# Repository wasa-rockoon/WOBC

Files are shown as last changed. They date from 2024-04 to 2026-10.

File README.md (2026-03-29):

View this project on [CADLAB.io](https://cadlab.io/project/27502). 

# WOBC

WOBCは，WASAロケットプロジェクトにおける電装関連の共通基盤を確立することを目的としたプロジェクトである．
開発した回路や基板の設計情報，プログラムといった資産を再利用しやすい形で整備することで，
開発スピードを向上させるとともに引き継ぎや教育を効率的に行えるようにする．

# 用語

## ユニット

単独で動作する，システムの基本単位．例：ロケット電装，CanSat電装，地上局

1つ以上のモジュールから構成される．

## モジュール

コンポーネントを一枚の基板上に配置した，物理的な単位．例：地上局モジュール，通信モジュール

モジュールには必ずマイコンが含まれ，コンポーネントを制御する．
ユニットを構成するモジュール間はバスで接続される．

## コンポーネント

ユニットを構成する，意味のある一つの機能単位．例：電源管理，姿勢決定，モーター駆動

ハードウェアおよびプログラムはコンポーネント単位で開発する．

## パケット

ユニットやコンポーネント間でやり取りするデータの形式．
詳しくは[WCPP](https://github.com/wasa-rockoon/WCPP)を参照．

# 開発

モジュールやコンポーネントは，全てこのリポジトリに格納する（Monorepoスタイル）．

## Gitの運用

- 開発者ごとに，`develop/your_name` ブランチを作成する．
- 全体に反映したい変更ができたらPull Requestを作成し，責任者にレビューを依頼する．
- コンポーネントおよびモジュール作成の際は自分のブランチとは別に，`feature/CompornentOrModule_name`ブランチを作成する．
- コンポーネント・モジュールが完成したらPull Requestを作成し，責任者にレビューを依頼する．
- 責任者は変更をレビューし，問題なければ`main`ブランチにマージする．（回路・基板のレビューには[CADLAB.io](https://cadlab.io/project/27502)を使うと便利)

## Github Copilotの学生無料

昨今コーディング作業に`AI Agent`の活用が主流になってきていると思います．ただ無料枠で利用していてもすぐトークンを使い切ってしまったり，選べるモデルが少なかったりと不便なことが多いかと思います．そこで個人的にはGithub Copilotの学生無料を利用することを推奨しています．導入方法については`ドキュメント`にあるリンクから参照してください．

## 作業ログ

`Github Copilot`の利用にあわせて，作業ログを作ることを習慣化してほしいと思います．おもにコーディング作業についてですが，

- 前にも同じようなエラーが出てたけど，どうやって解消したんだっけとか
- 過去にも似たようなもの作ってたらしいけど，資料が残っていないとか

色々と引継ぎが上手くいっていないような事象を見かけます．非常にもったいないというか二度手間なことが多いので，ちゃんとノウハウを蓄積できるようにしましょう．

具体的には `docs`のフォルダに`env:`毎でフォルダを作りその中で[template](docs/template.md)を参考にしてAIに作らせてください．タスク毎に作るのが良いかと思います．

# ドキュメント

- [develop](docs/develop.md): 詳細な開発の手順
- [kicad](docs/kicad.md): KiCADを用いた回路・基板設計マニュアル
- [github-copilot](docs/github-copilot.md): Github Copilotの導入マニュアル
- [components](docs/components.md): コンポーネントとその機能，インターフェースの一覧
- [modules](docs/modules.md): モジュールとその機能，構成コンポーネントの一覧
- [unit](docs/unit.md): ユニット一覧
- [library](docs/library.md): WOBCライブラリの使い方

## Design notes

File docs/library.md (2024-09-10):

# WOBCライブラリの使い方

`src/library`下にあるWOBCライブラリによって，コンポーネントやモジュールのソフトウェアを書くための機能が提供される．

# WOBCシステムアーキテクチャ

WOBC上でのソフトウェアでは，複数のコンポーネントが並行に実行され，それらの間のデータのやり取りがwcppパケットを用いたコマンドやテレメトリにより行われる．バスに送信されたパケットは，CANバスで繋がれた他のモジュール上で実行されているものも含めた他の全てのコンポーネントに届けられる．コンポーネントはコマンド（や必要に応じてテレメトリ）を受信し処理を行う．

パケット処理等の機能は`src/library/kernel`によって提供される．具体的には，パケットのデータ領域を確保する参照カウンタを備えたヒープ，コンポーネントに必要なパケットを振り分ける機能等が含まれる．

これらのカーネルが提供する機能は`process::Process`クラスのメンバを通してアクセスするほか，一部の機能は`kernel::`名前空間にあるシステムコールを通して利用する．

# コンポーネント

ソフトウェアにおいても，コンポーネントが最も基本的な開発単位である．コンポーネントの機能は以下に集約される．

- コマンドやテレメトリを受け取る．
- センサやアクチュエータなどのハードウェアを制御する．
- データ処理を行う．
- コマンドやテレメトリを送信する．

コンポーネント同士はコード上でも疎結合とするべきである．コンポーネント間のデータのやり取りは全てパケットを介して行い，グローバル変数を共有することは禁止される．

##　ソースファイルの構成

`src/components`下に，以下のようにコンポーネントのディレクトリを作成する．

```
src/components
├── MyCompo               # コンポーネントディレクトリ（ディレクトリ名はアッパーキャメルケース）
    ├── my_compo.h        # コンポーネントのコード（ファイル名はスネークケース）
    ├── my_compo.cpp        
    ├── sensor_driver.h   # コンポーネント内で使うドライバ等
    ├── sensor_driver.cpp 
├── AnotherCompo
```

`src/modules`下に，以下のようにモジュールのディレクトリを作成する．

```
src/modules
├── MyMod        # モジュールディレクトリ（ディレクトリ名はアッパーキャメルケース）
    ├── main.cpp # メイン         
├── AnotherMod
```

platformio.iniの`build_src_filter`でモジュールディレクトリを指定することで，envごとに用いる`main.cpp`を区別する．

## コンポーネントの実装

コンポーネントは`component`名前区間の中に[`process::Component`](../src/library/process/component.h)クラスを継承したクラスとして実装する．

```cpp
#include <library/wobc.h>

namespace component {

class MyCompo : public process::Component {
public:
  static const uint8_t component_id = 0x01;

  // コンポーネント名とidを指定して継承
  MyCompo(): process::Component("MyCompo", component_id) {}; 

protected:
  void setup() override; // start時に一度だけ呼ばれる．
  void loop() override;  // setupの後，無限回呼ばれる．
  void onCommand(const wcpp::Packet& command) override; // 自component_id宛のパケットが来たときに呼ばれる．
};
}
```

`setup`, `loop`, `onCommand`の各メンバ関数を必要に応じてoverrideすることで実装を追加する．ただし`loop`関数の中で無限ループを使わないこと．

## タイマー

[`process::Timer`](../src/library/process/timer.h)クラスを継承することで，一定時間ごとに処理を実行するタイマーを作ることができる．

```cpp
#include <library/wobc.h>

namespace component {

class MyCompo : public process::Component {
public:
  static const uint8_t component_id = 0x01;

  MyCompo(): process::Component("MyCompo", component_id) {}; 

protected:
  void setup() override {
    start(my_timer_); // タイマーを開始
  }

  class SampleTimer : public process::Timer {
  public:
    static const unsigned interval_ms = 1000;

    SampleTimer(): process::Timer("MyTimer", interval_ms) {}
    
  protected:
    void callback() override; // 実行する処理を記述
  } my_timer_;
};
}
```

## タスク

[`process::Task`](../src/library/process/task.h)クラスを継承することで，コンポーネント本体とは並行に処理を実行するタスクを作ることができる．

```cpp
#include <library/wobc.h>

namespace component {

class MyCompo : public process::Component {
public:
  static const uint8_t component_id = 0x01;

  MyCompo(): process::Component("MyCompo", component_id) {}; 

protected:
  void setup() override {
    start(my_task_); // タスクを開始
  }

  class SampleTask : public process::Task {
  public:
    SampleTask(): process::Timer("MyTask") {}
    
  protected:
    void setup() override; // start後に一回だけ呼ばれる
    void loop() override;  // start後に，terminate()で終了するまで無限回呼ばれる
  } my_task;
};
}
```

## パケット関連

上述した`Component`, `Timer`, `Task`はいずれも[`process::Process`](../src/library/process/process.h)クラスのサブクラスとなっている．，`process::Process`には以下のようなパケットの送受信等に関わるメンバ関数が備わっている．

### パケットの作成と送信

#### `wcpp::Packet newPacket(uint8_t size)`

データ領域を確保し．空のパケットを返す．

#### `wcpp::Packet decodePacket(const uint8_t* data)`

データ領域を確保し．`data`をデコードして得たパケットを返す．

#### `void sendPacket(const wcpp::Packet& packet)`

パケットをバス上に送信する．

#### `void sendPacket(const wcpp::Packet &packet, const Listener& exclude)`

パケットをバス上に送信する．その際，`exclude`で指定した`Listener`がパケットを受け取らないようにする．`Listener`でパケットの受信をトリガーに新たなパケットを送信するような場合に，自ら送信したパケットによって再び`Listener`がトリガーされるといったループを起こさないために用いる．

### パケットの受信

#### コマンドの受信

自コンポーネント宛のコマンドに対する処理は，`Component::onCommand(const wcpp::Packet& packet)`をオーバーロードして記述する．

#### その他のパケットの受信

上記以外のコマンドやテレメトリを受信する必要がある場合には，[`process::Process::Listener`](../src/library/kernel/listener.h)を用いる．

```cpp
#include <library/wobc.h>

namespace component {

class MyCompo : public process::Component {
public:
  static const uint8_t component_id = 0x01;
  static const unsigned listener_queue_size = 4;

  MyCompo(): process::Component("MyCompo", component_id) {}; 

protected:
  Listener my_listener_;

  void setup() override {
    // Listenerは何も指定しないと全てのパケットを受信する

    // テレメトリまたはコマンドのみ受信するようにフィルター可能
    my_listener_.telemetry(); 
    // my_listener_.command();
    
    // パケットid，コンポーネントid，送信元id, 送信先idでフィルター可能
    // それぞれビットマスクを指定できる（省略した場合は完全一致のみ通過）
    my_listener_.packet(id, mask);
    my_listener_.component(id, mask);
    my_listener_.unit_origin(id, mask);
    my_listener_.unit_dest(id, mask);

    listen(my_listener_, listener_queue_size); // 受信開始
  }
  void loop() override {
    while (my_listener_) { // キューにパケットがある場合
      const wcpp::Packet& packet = my_listener_.pop(); // キューから一つ取り出す
      // Listenerがパケットを受信したときの処理
    }
  }
  void onCommand(const wcpp::Packet& command) override {
    // 自コンポーネント宛のコマンドを受信したときの処理
  }
};
}
```

### ログとエラー出力

ログやエラーの出力もパケットを用いて行う．特に`SerialBus`を用いている場合には，直接`Serial.print`を用いてログを出力することはシリアル出力が汚染されるのみならず並列実行によりクラッシュする可能性があるため推奨されない．

#### void LOG(const char* format, Args... args)

デバッグ等のためのログパケット(id=0x23='#')を出力する．メッセージ，記述したファイル名，行番号をエントリに含むパケットが送信される．
`printf`と同様に，フォーマット文字列と可変長の引数を与えることができる．

#### void error(const char* code, const char* format, Args... args)
エラーパケット(id=0x21='!')を出力する．4文字以下のエラーコードと，メッセージを含むパケットが送信される．
`printf`と同様に，フォーマット文字列と可変長の引数を与えることができる．

### パケットの不揮発メモリへの保存

#### `bool storePacket(const wcpp::Packet& packet)`

コンポーネントidとパケットidをキーに，パケットを不揮発メモリに保存する．すでに保存されているパケットがある場合は上書き保存される．

#### `wcpp::Packet loadPacket(uint8_t packet_id)`

コンポーネントidと`packet_id`をキーに，パケットを不揮発メモリから読み込む．保存されているパケットがない場合には`wcpp::Packet::null()`を返す．

#### `bool storeOnCommand(uint8_t packet_id)`

コンポーネントの`setup`内で呼んでおくと，指定した`packet_id`のコマンドを受信したとき自動的に不揮発メモリに上書き保存されるようになる．設定値をリモートコマンドで変更できるようにするのに便利である．

### その他のProcessメンバ関数

#### void delay(unsigned ms)

Arduinoで提供される`delay`の代わりに用いる．

# モジュール

モジュールはマイコンに書き込むプログラムの単位であり，`main.cpp`に記述する．
`setup`内で搭載するコンポーネントの初期化等を行う．ユニット内にただ一つ存在するMainコンポーネントを搭載するMainモジュールの場合は，これも記述する．

### Mainモジュールの場合
```cpp
constexpr uint8_t module_id = 0xF0;
constexpr uint8_t unit_id = 0x01;

// Core機能
core::CANBus can_bus(44, 43);
core::SerialBus serial_bus(Serial);

// コンポーネント
component::MyComp my_comp;

// Mainコンポーネント
class Main: public process::Component {
public:
  Main(): process::Component("Main", 0x00) {} // Mainコンポーネントのidは0x00

  void setup() override;
  void loop() override;
} main_;

void setup() {
  // put your setup code here, to run once:
  Serial.begin(115200);

  kernel::setUnitId(unit_id); // unit id を設定
  
  // モジュールidを確認
  // もし前回書き込んだモジュールidと異なる場合は，実行を中断して回路を保護する
  // モジュールidを変更したい場合は kernel::begin(module_id, false) とする
  if (!kernel::begin(module_id, true)) return;

  // Core機能を起動
  can_bus.begin();
  serial_bus.begin();

  delay(1000);

  // コンポーネントを起動
  my_comp.begin();
  main_.begin();
}
```

### Main以外のモジュールの場合

Mainモジュールと接続されていれば，Mainモジュールで指定したunit_idを`kernel::unit_id()`で取得できる．

```cpp
constexpr uint8_t module_id = 0xF1;

// Core機能
core::CANBus can_bus(44, 43);
core::SerialBus serial_bus(Serial);

// コンポーネント
component::MyComp my_comp;

void setup() {
  // put your setup code here, to run once:
  Serial.begin(115200);

  if (!kernel::begin(module_id, true)) return;

  // Core機能を起動
  can_bus.begin();
  serial_bus.begin();

  delay(1000);

  // コンポーネントを起動
  my_comp.begin();
}
```

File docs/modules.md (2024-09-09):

# モジュール一覧

# Tracker(T, 0x54)
GNSS及び気圧温湿度センサを搭載し，位置情報と高度といった成層圏気球実験において必要最小限の情報を送信するモジュール．LiPoの充放電の機能を有し，電源状態のモニタリングを行う．

## コンポーネント構成
|コンポーネント名|ID|
| --- | --- |
| ESP32Core | 0 |
| LiPoPower | 1 |
| Logger | ? |
| GPSActive | ? |
| LoRa | 11~18 |
| Pressure | ? |

# GS(G, 0x47)
機体からのダウンリンクの受信およびアップリンクを行う地上局の中心となるモジュール自身の位置がわかるようにGNSSを搭載する．サーバーの更新を行う．

## コンポーネント構成
|コンポーネント名|ID|
| --- | --- |
| ESP32Core | 0 |
| LiPoPowerSimple | 1 |
| Logger | ? |
| ModuleIFSimple | - |
| GPSPassive | ? |

# LoRa(L, 0x4C)
LoRaモジュールを2機搭載しアップリンクとダウンリンクの送受信を行う．

## コンポーネント構成
|コンポーネント名|ID|
| --- | --- |
| PR2040Core | 0 |
| ModuleIFSimple | - |
| LoRa | 11~18 |

# Controller(C, 0x43)
主に地上局で用いるが，インジケータとなるLEDやLCDと，コマンド送信用のスイッチを搭載する．

## コンポーネント構成
|コンポーネント名|ID|
| --- | --- |
| PR2040Core | 0 |
| ModuleIFSimple | - |
| LCD | 25 |

# MissionBus(M, ox4D)
ミッション電装の中心となるモジュール．GMSS，気圧温湿度，6軸，地磁気センサによって機体の情報を取得し，LoRaで送信を行う機能を有する．

## コンポーネント構成
|コンポーネント名|ID|
| --- | --- |
| ESP32Core | 0 |
| LiPoPower | 1 |
| Logger | ? |
| ModuleIF | 3~10 |
| GPSActive | |
| LoRa | 11~18 |
| Pressure | ? |
| IMU | |

# IGN(I, 0x49)
点火回路を有し，モデルロケットの点火を行うモジュール．

## コンポーネント構成
|コンポーネント名|ID|
| --- | --- |
| ERP2040Core | 0 |
| ModuleIFSimple | - |
| Ignite | |

# RCS(V, 0x56)
姿勢制御のためのスラスタの駆動を行う．そのほか圧縮空気タンクの圧力とロードセルのデータの取得を行う．

## コンポーネント構成
|コンポーネント名|ID|
| --- | --- |
| ERP2040Core | 0 |
| ModuleIFSimple | - |
| RCS | |
| HX711 | |
| TankPressure | |

# Rocket(R, 0x72)
ロケットに搭載する小型電装．GMSS，気圧温湿度，6軸，地磁気センサによって機体の情報を取得し，LoRaで送信を行う機能を有する．

## コンポーネント構成
|コンポーネント名|ID|
| --- | --- |
| ESP32Core | 0 |
| LiPoPower | 1 |
| Logger | ? |
| ModuleIF | 3~10 |
| GPSActive | |
| LoRa | 11~18 |
| Pressure | ? |
| IMU | |

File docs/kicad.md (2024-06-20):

# KiCADを用いた回路・基板設計マニュアル

# 新規コンポーネント作成

`hardware/components/Tempelate/`を同階層にコピーし，
ディレクトリおよび回路図・基板ファイルの名前をコンポート名に変更する．

# コンポーネントの回路設計

## 部品の配置

使用する部品を選び，配置する．

KiCADのライブラリにない部品を使いたい場合は，ネットで探すか，自作する．
自作したシンボルは`hardware/library/WOBCLibrary.kicad_sym`に，
フットプリントは`hardware/libirary/WOBCLibrary.pretty`に追加しておく．

トランジスタのように一般的な部品は，特定の型番のものではなく一般的な記号のものを使う．

## 電源と配線

部品同士を配線する．
電源に関しては以下のシンボルを使う．

- VDD: 3.3V系の電源．IC類の電源は基本的にこれを用いる．
- GND
- VBUS: USBコネクタから供給される5V電源．
- VPP: 電池の出力そのまま等，VDDの上流の電源．
- +BATT: RTCやGNSS用のバックアップ電源．

ICの電源ピンには100nF程度のバイパスコンデンサを付ける．

## 入出力ラベルの設定

電源以外に外部と接続したいピンは，階層ラベルをつける．
階層ラベル名のprefixにコンポーネント名をつける必要はない．

## シンボルのアノテーション

Symbol reference designatorを使用し，
各シンボルについている番号（`R0`，`Q1`など）を振り直す．
モジュール作成時にインポートする作業のため，番号は100から始まるようにする．

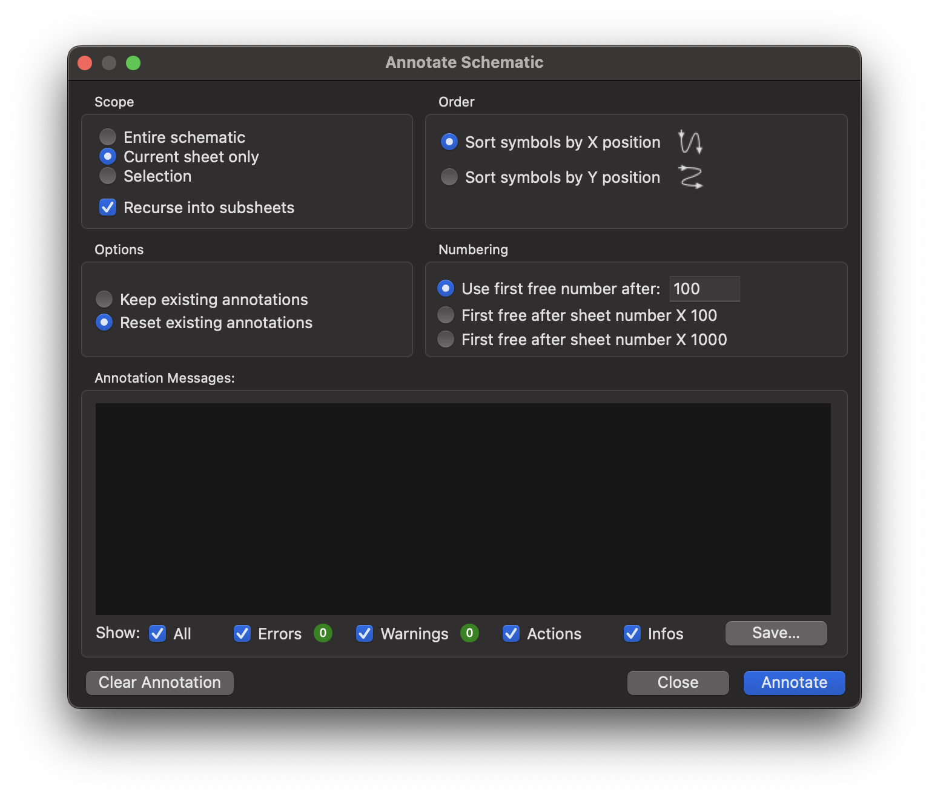
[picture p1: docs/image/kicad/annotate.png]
Annotate


## フットプリントの割り当て

Footprint assignment toolを使用し，シンボルにフットプリントを割り当てる．

特によく使う部品のフットプリントに関しては，

| カテゴリ | |
|----|---|
| 抵抗 | 信号用は 0402(1005) サイズを用いる．|
| 積層セラミックコンデンサ | 1uF以下は0402(1005) サイズ，大容量の電源用には0603(1608)や0805(2012)サイズを目安に用いる．|

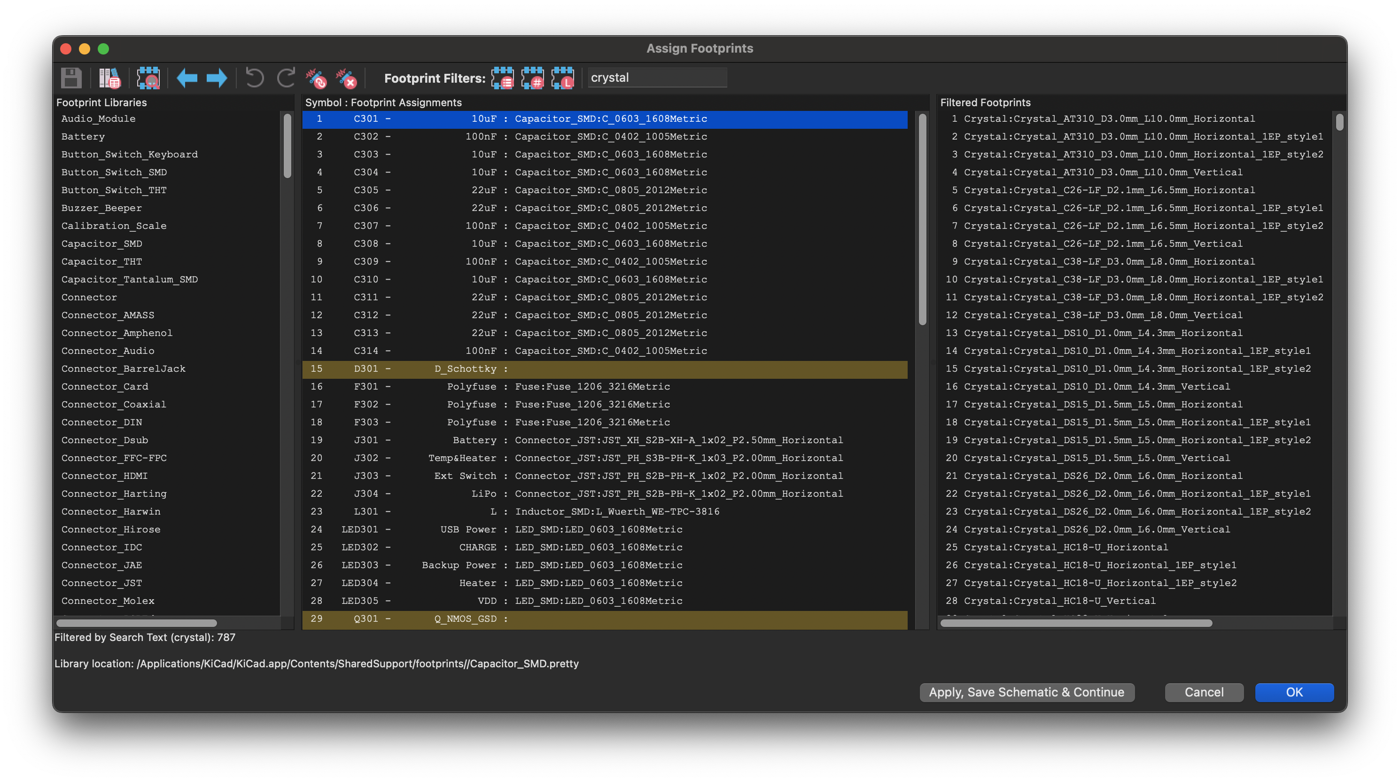
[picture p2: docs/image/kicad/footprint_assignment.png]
Footprint Asignment


## LCSC部品番号の割り当て

PCBAサービスで実装したい部品について，
[JLCPCB Parts Lib](https://jlcpcb.com/parts)で探した部品の番号
（JLCPCB Parts # とある，Cから始まる番号）をシンボルに設定する．
シンボルに`LCSC`というフィールドを追加し，部品番号を入力する．

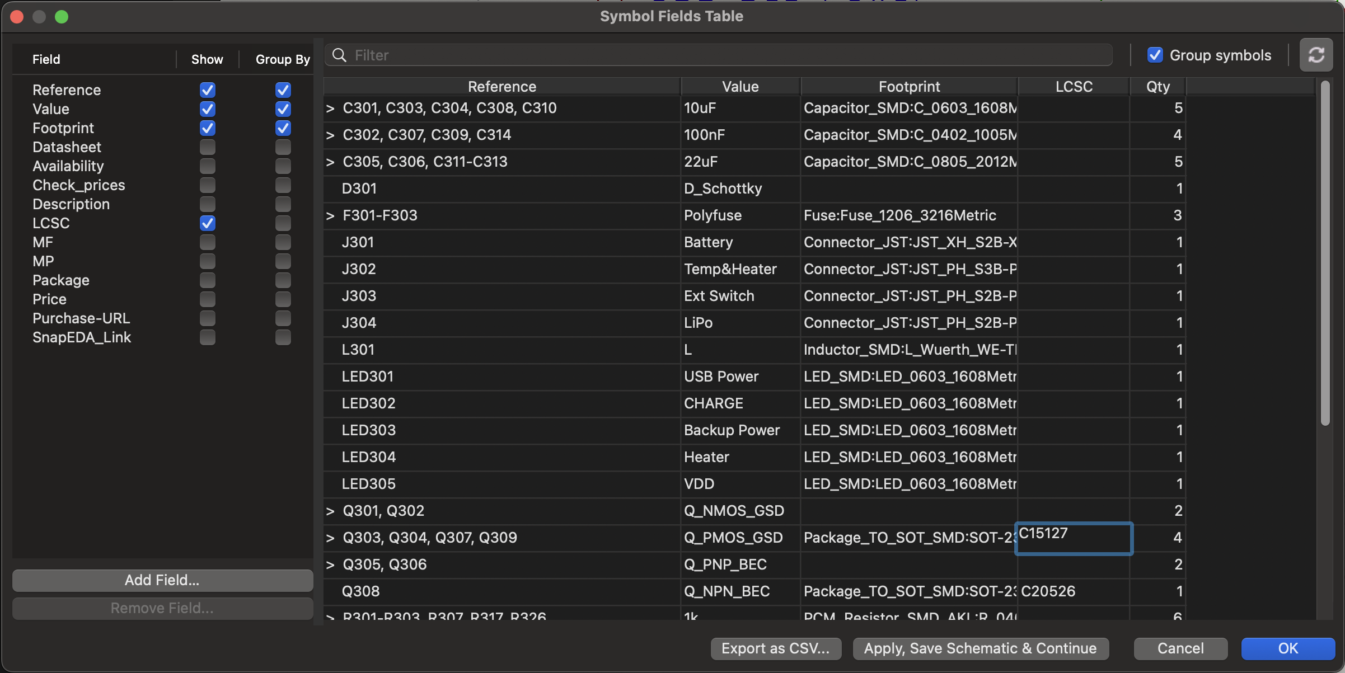
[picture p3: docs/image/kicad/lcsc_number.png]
LCSC Parts Number


## Electorical Rule Check の実行

ELCを実行し，回路に間違いがないか確認する．
使っていないピンには no-conenction-flag (バツ印)を設定して，
エラーが出ないようにしておく．

# コンポーネントの基板設計

通常はモジュールごとに基板設計を行うが，コンポーネントの回路が複雑で部品点数が多いなどの
理由で基板設計データも再利用したいときには，コンポーネントごとに基板設計を行ってもよい．

注意点等はモジュールの基板設計の項目を参照．

# 新規モジュール作成

`hardware/modules/Tempelate/`を同階層にコピーし，
ディレクトリおよび回路図・基板ファイルの名前をモジュール名に変更する．

# モジュールの回路設計

## コンポーネントの挿入

モジュールの設計をする際はコンポーネントをコピーして使用する．

シートを追加し，`Sheetname`と`Sheetfile`に適当に名前を付ける．

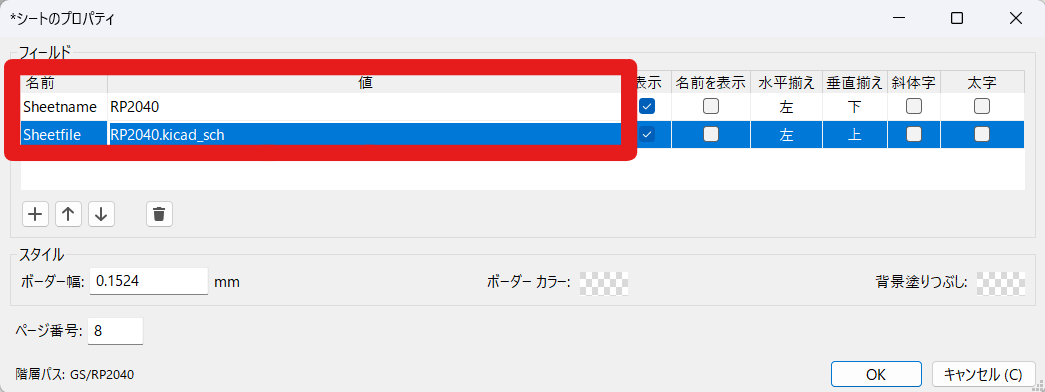
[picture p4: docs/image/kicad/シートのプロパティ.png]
Sheet Properties


コンポーネントごとに基板設計を行っている場合は，以下の手順で基板設計データをコピーする．

1. モジュールプロジェクトを開く
2. 上述の通り，回路エディタで階層シートを追加する．
3. コピーしたいコンポーネントの回路エディタを開き，すべてのシンボルをコピーして，モジュールプロジェクトの階層シート内に張り付ける．
4. モジュールプロジェクトの階層シート内のみでシンボルのアノテーションを行い部品に100から始まる番号を振り直す（階層シート内の部品のみ）
5. コピーしたいコンポーネントの基板エディタを全選択しコピーして，モジュールプロジェクトの基板エディタに張り付ける．
6. ペーストした基板の部品と回路図を結びつけるため，基板エディタのUpdate PCB from Schematic(回路図から基板を更新) ツールで，Re-link ... on their reference designators(リファレンス指定子に基づいいて...) にチェックを入れて Update PCB(基板を更新)
7. 回路図エディタで回路図全体でシンボルのアノテーションを行い，モジュールの全ての部品について0から始まる部品を振り直す
8. 基板エディタで振り直した番号を反映させるため，Re-link ... on their reference designatorsのチェックを外してUpdate PCB
9. さらにモジュールにコンポーネントを追加する場合，1~8の手順を繰り返す．

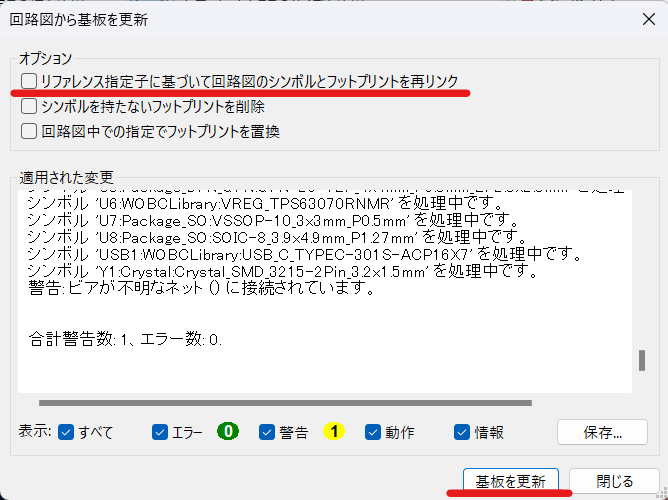
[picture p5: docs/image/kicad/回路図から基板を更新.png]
Update PCB


## 配線

シートを右クリックして`Import Sheet Pin`で階層ラベルに設定した入出力ピンを表示し，
コンポーネント間を配線する．

# モジュールの基板設計

[ノイズ対策.COM](https://www.noise-counterplan.com)などを参考に.

## ベース基板の決定

モジュールは基本的に，60mm x 60mm x 1mm のサイズを基準としたベース基板上に実装する．
WOBCLibrary内の`BaseBoard`を用いる．

## 部品の配置

PCBAサービスで実装する部品は必ず，手実装する部品もなるべく片面に配置する．

## 配線

[JLCPCBの寸法ルール](https://jlcpcb.com/capabilities/pcb-capabilities)
を破らないように，配線幅やクリアランスをとる．

- 基板厚さ：基本的に1mmとする．
- ビア：基本的に径0.5mm，ドリル径0.3mm
- 信号線：0.2mm 以上
- 電源線：0.4mm, 0.8mm などなるべく太く．1Aで1mmが目安
- 無線信号：曲線で配線幅 1.5mm〜2.0mm，裏面にGNDプレーンを配置して50Ωのマイクロストリップ線路にする
- USB信号：配線幅 0.8mm，配線間隔 0.2mm，裏面にGNDプレーンを配置して90Ωの差動マイクロストリップ線路にする（配線が長い場合）
- 無線信号：曲線で配線幅 1.5mm〜2.0mm，裏面にGNDプレーンを配置して50Ωのマイクロストリップ線路にする
- CAN信号：配線幅 0.4mm，配線間隔 0.2mm，裏面にGNDプレーンを配置して120Ωの差動マイクロストリップ線路にする

## シルクの設定

コネクタやLEDなどが何を表すかわかるように，基板上に記しておく．

部品番号については，手で実装しない部品で書くスペースがない場合は消してもよい．

部品や他の文字，ビアと被らないように配置する．
文字サイズは最低0.8mm以上，できれば1mm以上を推奨．

署名やロゴマークなどを入れてもよい．

## ベタGNDの設定

なるべくスタブがないようにする．
外周やスタブになるところにはビアを配置する．

## Design Rule Check の実行

DLCを実行し，未配線やクリアランス違反がないか確認する．

## ガーバーファイルの書き出し

KiCADプラグインのJLCPCB Toolsを用いてガーバーファイルを書き出す．

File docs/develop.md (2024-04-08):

# 開発環境

## 回路・基板設計

- KiCAD

## プログラム製作・書き込み・デバッグ

- Platform IO

## ソフトウェアスタック

- Arduino
- FreeRTOS

## 製作

基板はプリント基板製造サービスを，はんだ付けは（特に表面実装部品は）部品実装（PCBA）サービスを利用することを推奨する．
ここでは，プリント基板製造および部品購入・実装にJLCPCBを利用する場合について解説する．

# コンポーネントの開発

作りたいユニットが既存のコンポーネントの組み合わせだけでは求める機能を得られない場合，
新規にコンポーネントを開発することになる．コンポーネントの開発は以下のような流れとなる．

## 概念設計

必要な機能を再利用可能な最小単位に分割し，それぞれをコンポーネントとする．
コンポーネントに求められる機能や性能要求，何を入出力とするか整理し，必要な部品の検討をつける．

作るコンポーネントが決定したら，コンポーネント名およびIDを決定して
(コンポーネント一覧)[docs/components]に記載する．

コンポーネント名の付け方は以下の通り．

- 英数字のみを使う．日本語は使わない．
- 大文字から始まるキャメルケースを使う．
- コンポーネントの機能を表す適切な抽象度合いの名前にする．部品名や型番のように具体的すぎる名前や，反対に抽象的すぎて内容が想像しづらい名前は避ける．（例：`E220`→具体的すぎる，`Communication`→抽象的すぎる，`LoRa`→適切）

## 部品選定

概念設計で決めた機能や性能を有する電子部品を探す．

PCBAサービスを利用できること，小型，低価格，流通量の多さといった理由から，表面実装部品を主に用いるとよい．
表面実装部品はJLCPCBの部品ライブラリから，
手で実装するスルーホール部品などは秋月，千石，Digikey，Switch Science などから探す．

この際，できる限り以下のような点を満たすものから選ぶとよい．

- データシートに記された定格が，性能要求を余裕をもって満たすもの
- 安く入手性が良い（在庫が多い）もの
- JLCPCB Partsの中では，Basic Part または Preffered Part（手数料がかからない）であるもの
- 表面実装部品なら，ブレッドボードで試作するためにDIP版またはブレークアウト基板，開発キット等が入手できるもの
- 製造元のHPや販売サイト，あるいは個人のブログなどを調べることで使用方法がよくわかるもの
- Arduinoのライブラリが存在し，すぐ使えるもの
- 他コンポーネントですでに使われており共通のもの

## 回路設計

部品を探すと同時に，回路設計を始める．
部品のデータシートにある応用回路例や，ネット上の製作例を参考に設計するとよい．

具体的には(KiCADマニュアル)[docs/kicad.md]を参照．

## 試作

部品や回路が想定通り動くか，ブレッドボードを用いて試作し，回路を設計する．
同時にプログラム製作も進めるとよい．

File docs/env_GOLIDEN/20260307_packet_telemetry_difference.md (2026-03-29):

# Packet::telemetry(2引数版) と Packet::telemetry(5引数版) の違い

作業者：narrow

---

## 目標
- `Packet::telemetry(uint8_t packet_id, uint8_t component_id)`
- `Packet::telemetry(uint8_t packet_id, uint8_t component_id, uint8_t origin_unit_id, uint8_t dest_unit_id, uint16_t sequence)`
の違いが知りたい

---

## 実装の違い

### 2引数版（ローカル形式）
実装: `src/library/wcpp/cpp/Packet.cpp` の 398-404 付近

- `buf_[1] = packet_id | packet_type_mask`（telemetry種別ビットを立てる）
- `buf_[2] = component_id`
- `buf_[3] = unit_id_local`
- `resize(0, 4, buf_[0])` によりヘッダ長4バイトにする

### 5引数版（リモート形式）
実装: `src/library/wcpp/cpp/Packet.cpp` の 406-416 付近

- `buf_[1] = packet_id | packet_type_mask`（telemetry種別ビットを立てる）
- `buf_[2] = component_id`
- `buf_[3] = origin_unit_id`
- `buf_[4] = dest_unit_id`
- `buf_[5] = sequence & 0xFF`
- `buf_[6] = sequence >> 8`
- `resize(0, 7, buf_[0])` によりヘッダ長7バイトにする

### 共通点
- どちらも telemetry パケットを作る（種別は同じ）
- 違いは「ヘッダ情報量（4バイト or 7バイト）」

---

## 内部判定への影響

`packet.h` 側では以下の判定になっている。

- `header_size()` は `isLocal() ? 4 : 7`
- `isLocal()` は `buf_[3] == unit_id_local (0x00)`

つまり、5引数版であっても `origin_unit_id` に `0x00` を入れると local 扱いになる。
その場合、`dest_unit_id()` や `sequence()` の見え方が意図とズレる可能性があるため、通常は `origin_unit_id` に実際のユニットIDを入れる。

---

## 使い方の違い

### 2引数版を使う場面
- 同一ユニット内の内部バスで完結するテレメトリ
- 余計なヘッダを持たせず軽くしたいとき

### 5引数版を使う場面
- ユニット間転送や中継を想定するテレメトリ
- `origin/dest/sequence` を明示したいとき
- ログ解析時に経路情報を残したいとき

---

## 今回の LiPoPower の行について

対象行:

```cpp
packet1.telemetry(Powertelemetry_id, lipo_power_.component_id, unit_id_, 0xFF, 1234);
```

これは **5引数版** を使っており、

- `origin = unit_id_`
- `dest = 0xFF`
- `sequence = 1234`

を明示したテレメトリになっている。

---

## 参照ファイル
- `src/library/wcpp/cpp/Packet.cpp`
- `src/library/wcpp/cpp/packet.h`
- `src/components/LiPoPower/lipo_power.cpp`

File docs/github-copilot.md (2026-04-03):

# Github Copilotを学生無料で導入するためのマニュアル(適宜更新していきましょう！)

最終更新日：2026/04/03

githubのアカウントはすでにある前提で書いていこうと思います．[URL](https://qiita.com/melonsode/items/3602ea6441ca82e43c5a)この記事にまとまっていることを参考にしつつ，github-copilot君と書いています．時間が経つと色々変わることもあると思うので，適宜修正してください．

---

## 0. このマニュアルの対象

- 対象：**学生向けの無料特典（GitHub Education 経由）で GitHub Copilot を使いたい人**
- 前提：GitHubアカウントをすでに持っている
- 使用環境の例：VS Code（Windows / macOS / Linux）

> ※GitHubの画面UIや申請項目は時期によって変わります。文言が少し違っていても、
> 「GitHub Educationで学生認証 → Copilotを有効化」の流れは同じです。

## 1. 事前に準備するもの（前提の追記）

学生認証で詰まりやすいので、最初に揃えるとスムーズです。

- 学校メールアドレス（`fuji.waseda.jp` などgithubに登録済みのもの）。登録するにはgithubの自分のアカウントの`setting`から`email`を選択して`add email`から追加してください。

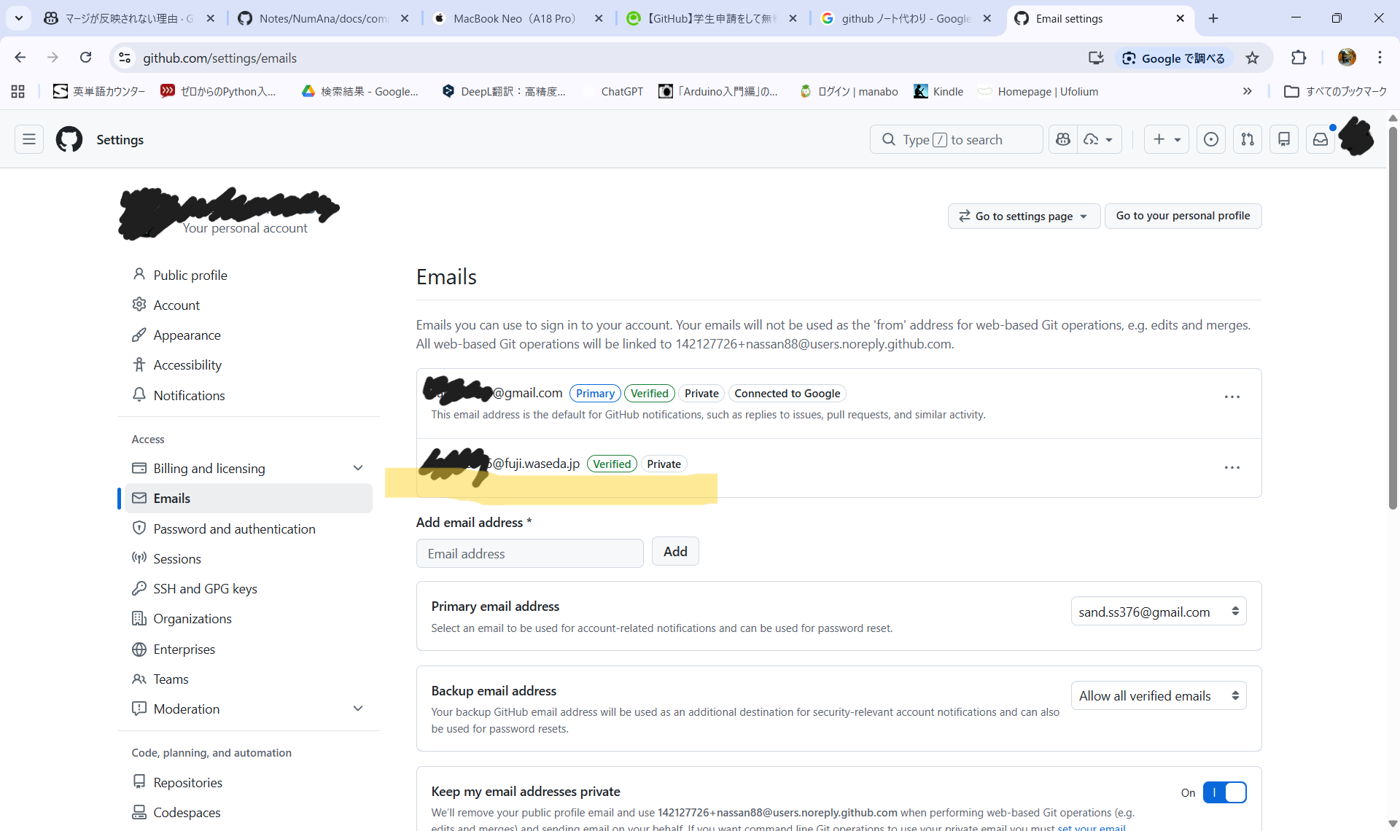
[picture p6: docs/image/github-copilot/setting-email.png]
setting-email


> `Verified`となっていれば大丈夫です。

- 在学を証明できるもの（例：学生証、在学証明書、履修画面のスクリーンショット）。

> 一番手軽なのは、`マイ早稲田 -> ログイン -> 個人情報照会・変更 -> 学生基本情報`にある画面のスクショですね。

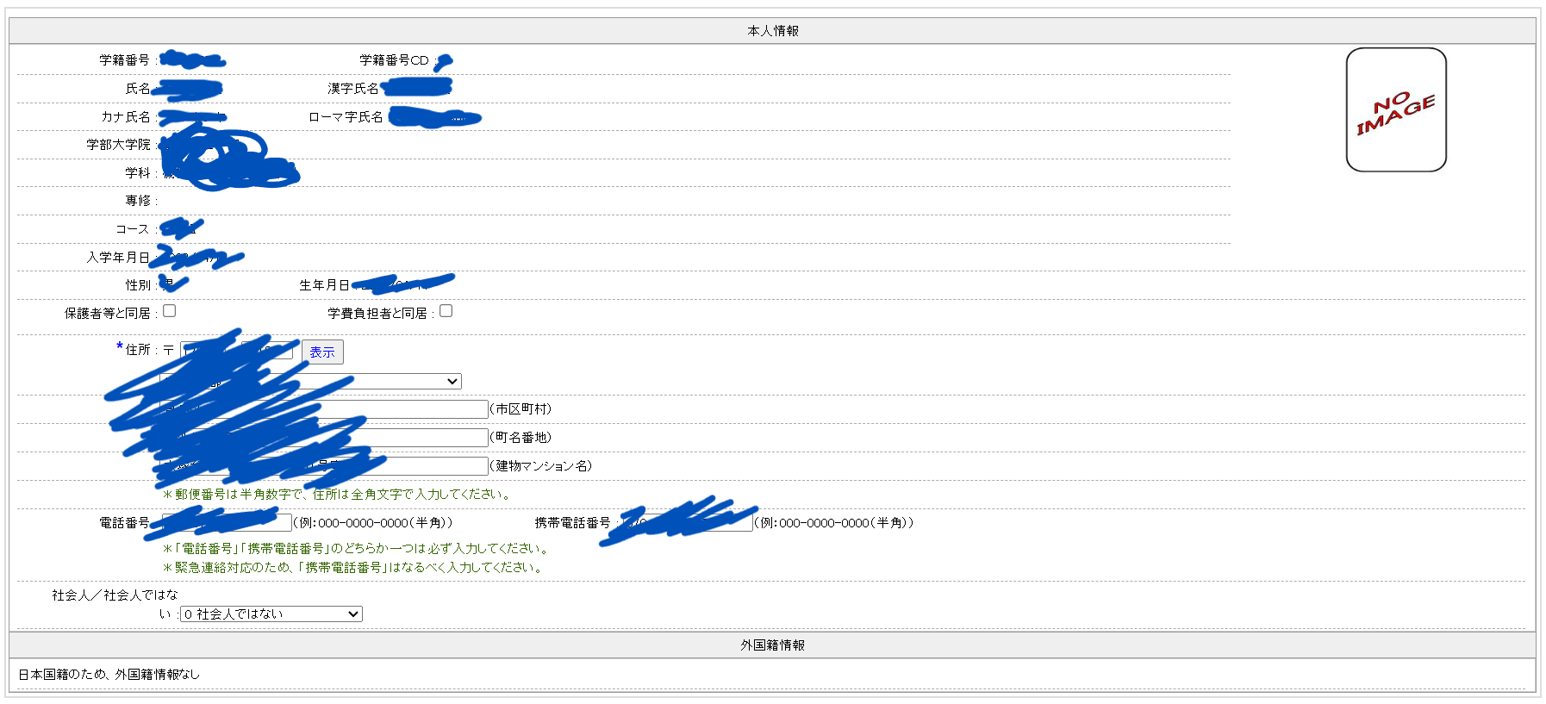
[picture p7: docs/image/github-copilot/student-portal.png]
student-portal


> 次点で学生証です。

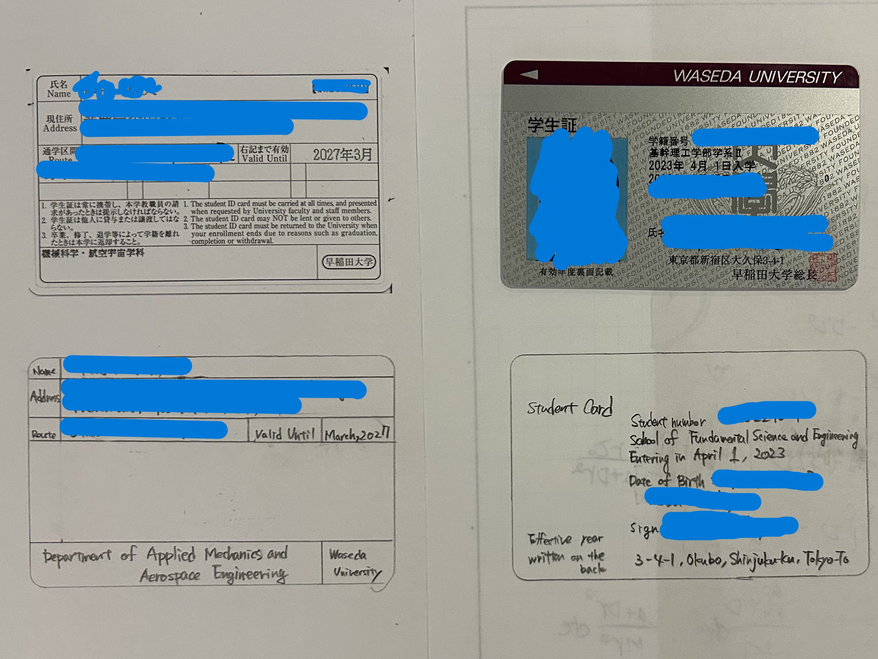
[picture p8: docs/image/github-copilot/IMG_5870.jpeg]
student-ID-card


> 学生証の場合、画像のように学生証の表裏とそれぞれの英訳をつけた画像を用意してください。

- GitHubアカウント情報（2段階認証を有効化しておくと安心）

## 2. GitHub Education の学生認証を行う

#### 2-1 入力画面まで移動
- `GitHub` にログインする
- `GitHub Education`（Student Developer Pack）と検索して一番上の申請ページを開いて`Join GitHub Education`をクリック

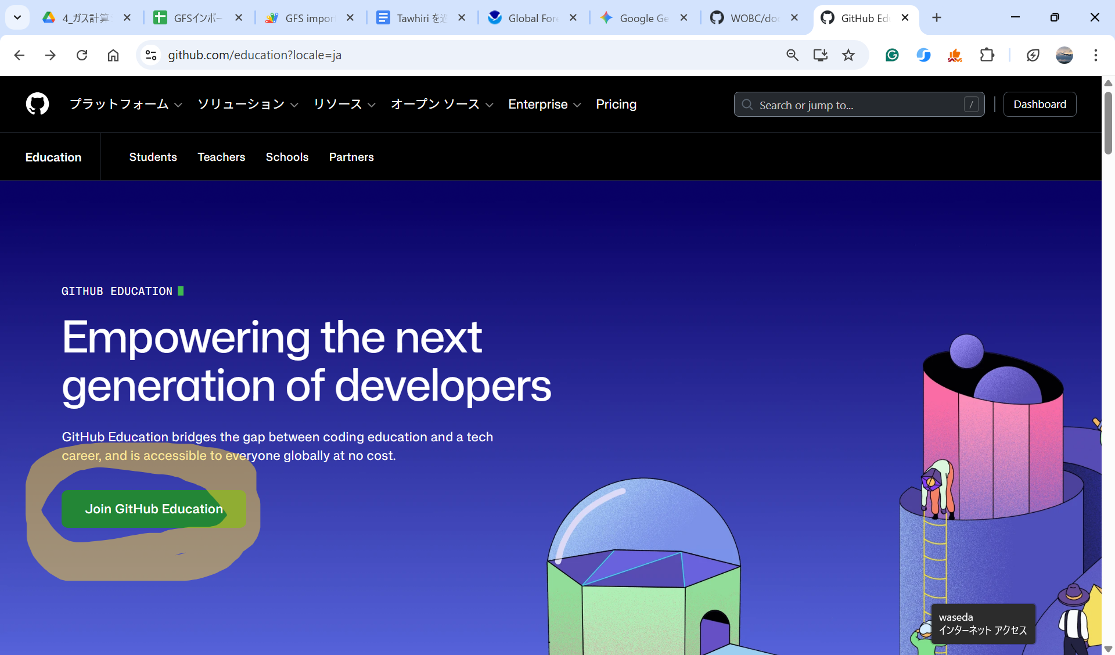
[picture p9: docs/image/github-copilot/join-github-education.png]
github-education


- 次の画面で`Start an application`をクリック

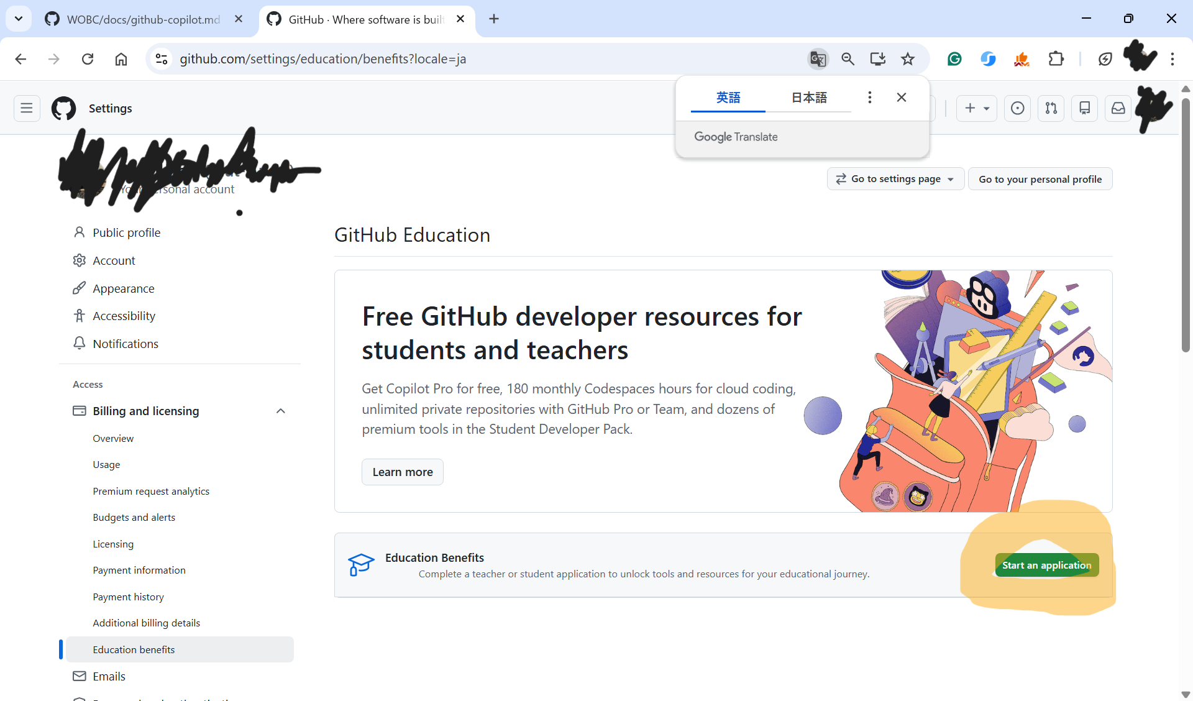
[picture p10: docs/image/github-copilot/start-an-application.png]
start-an-application


#### 2-2 学校情報を入力し、在学証明資料をアップロード
- まず、生徒か教員かを聞かれるので`Student`を選択してください

- 次に自分の大学を検索して選択してください

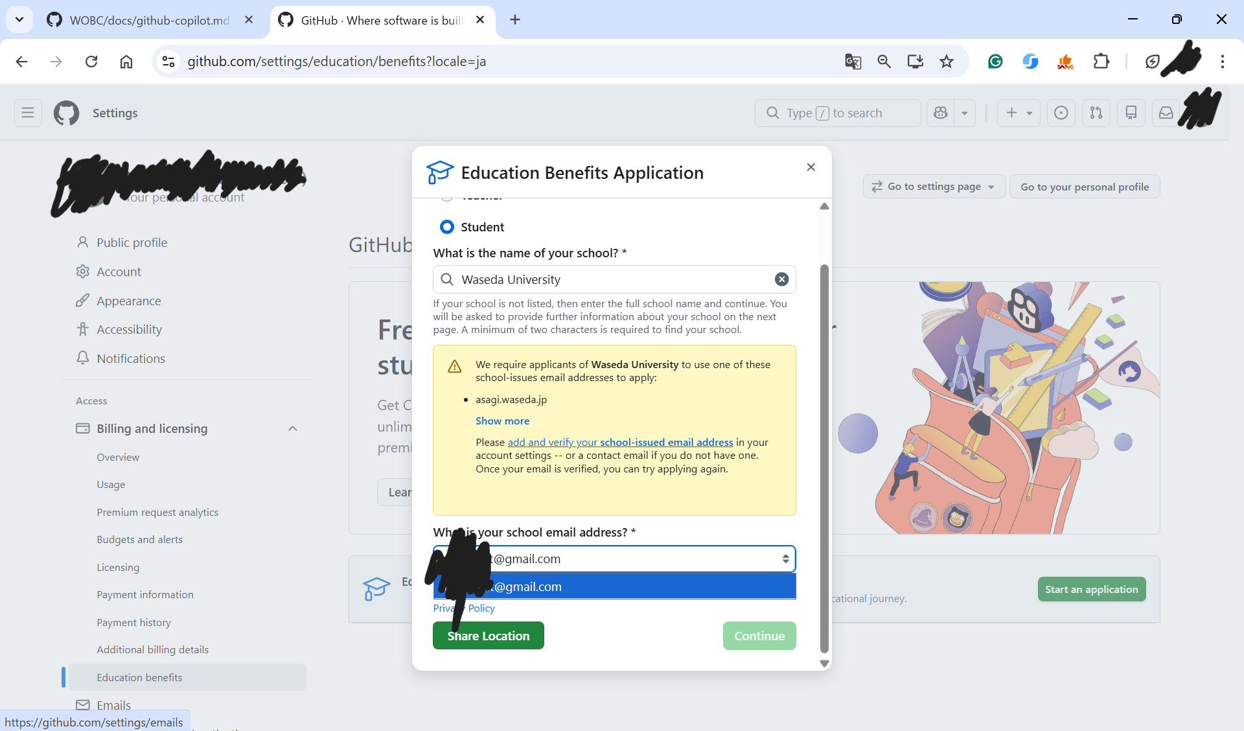
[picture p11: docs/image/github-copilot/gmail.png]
emailまで①


> gmailだと登録できないのでご注意ください。

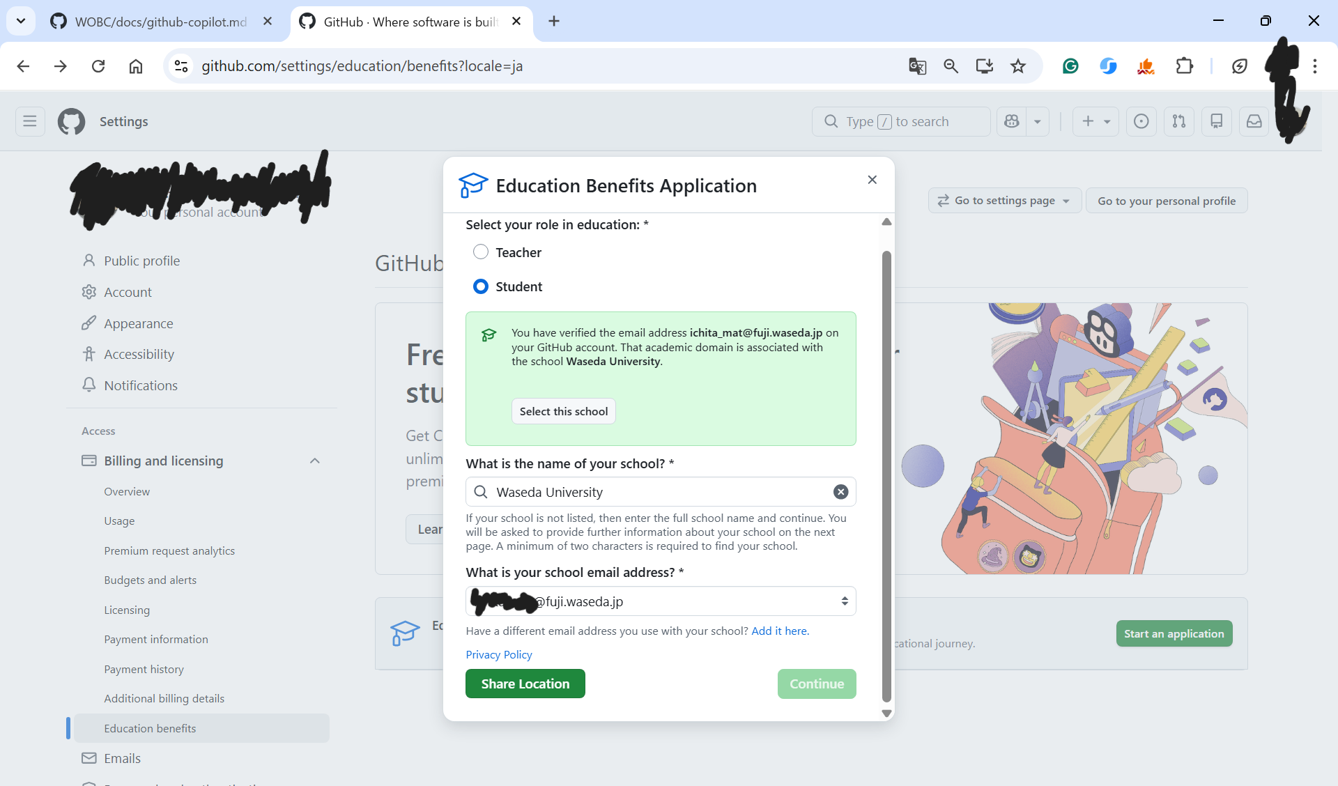
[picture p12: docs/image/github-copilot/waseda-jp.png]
emailまで②


- メールアドレスまで入力が済んだら`Share Location`をクリックして、`Continue`が緑になったらクリックして次に進んでください。

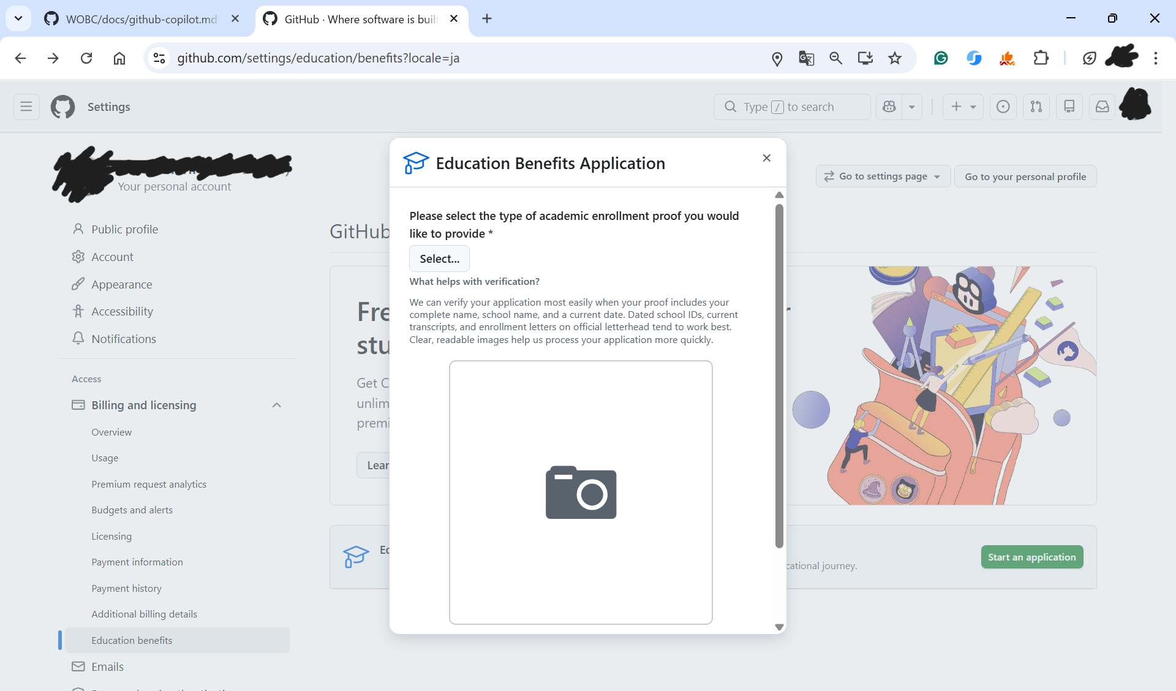
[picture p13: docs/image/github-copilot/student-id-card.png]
学生証アップロード


- ここで学生基本情報のスクショが学生証の画像をアップロードをしてください。
- 学生基本情報のスクショの場合は左上の`Select...`を選択して`8`のStudent Potalなどと書いてるものを選択してください。
- 学生証の場合は`1`にStudent ID cardの選択肢があるかと思います。

#### 2-3. 申請を送信

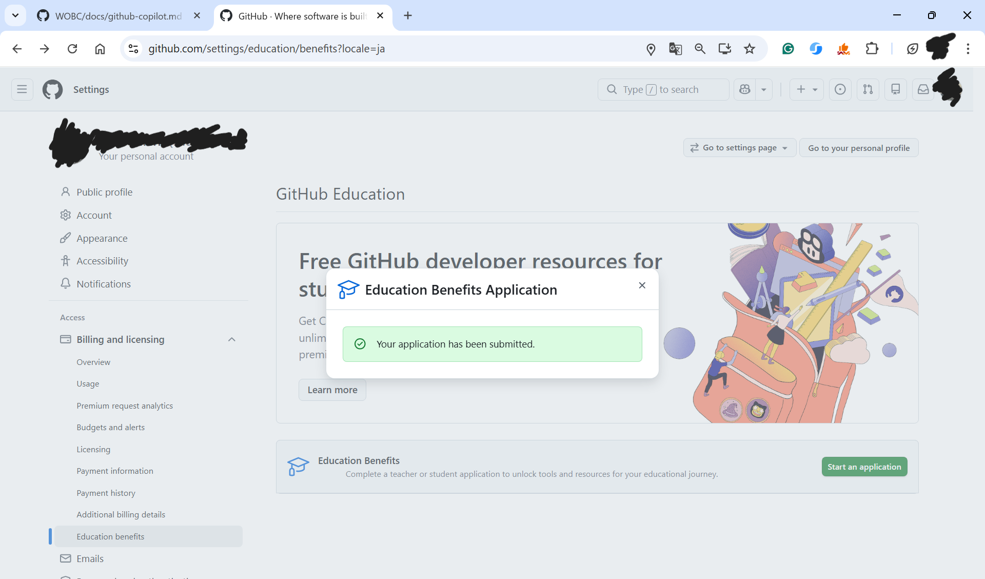
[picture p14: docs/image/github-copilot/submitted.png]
Submitted


- この画面まで来たらひとまず完了です。

#### 2-4. 審査結果メールを待つ（即時〜数日程度）
- 登録したメールアドレスに連絡メールが来ます。
- もしくは、うまくいっていると`GitHub` の `自分のアイコン -> settings -> Billing and licensing -> Education benefits` にお祝いメッセージ的なものが届きます。

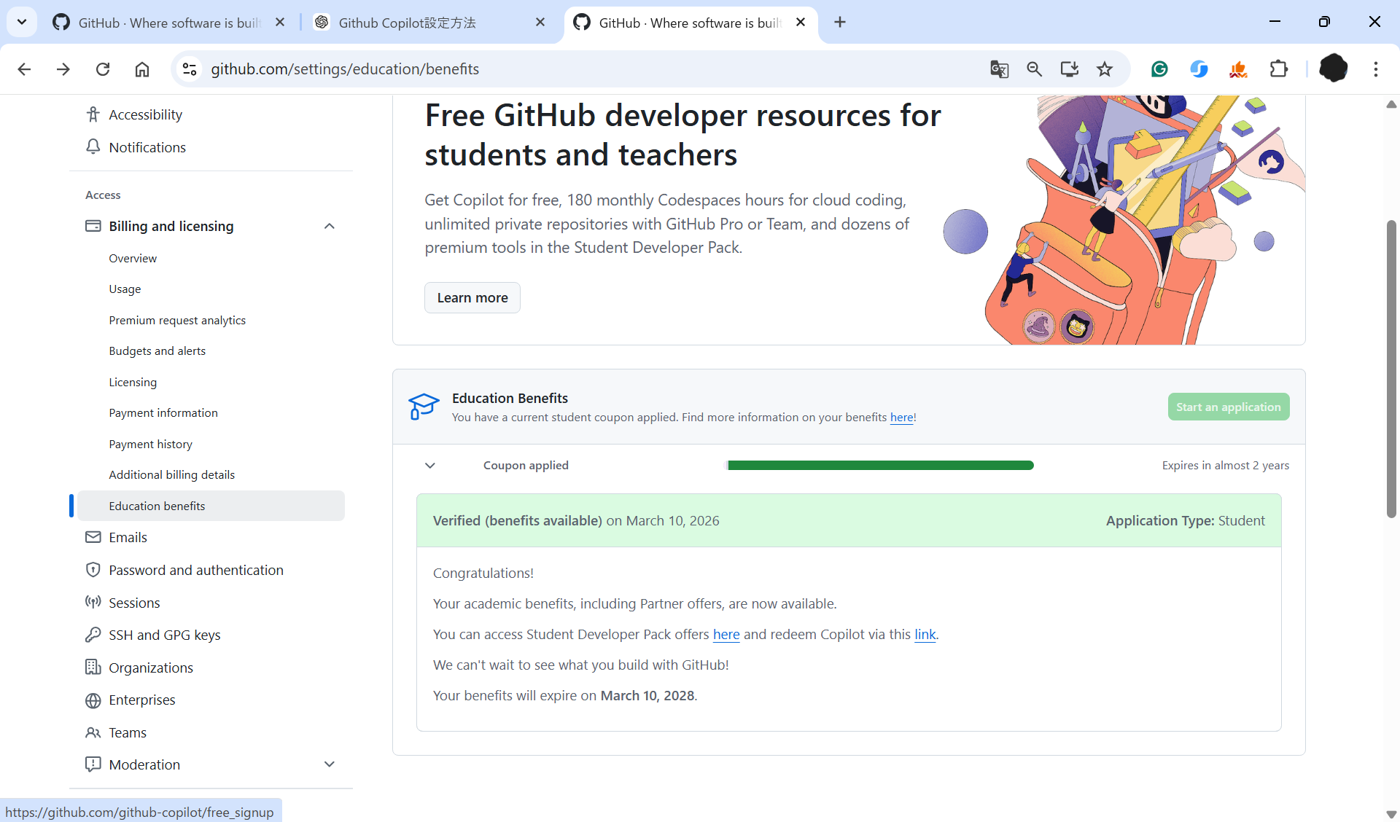
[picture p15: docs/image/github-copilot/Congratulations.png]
Congratulations


- 上手くいかなかった場合も、修正点等のメッセージが届きます。

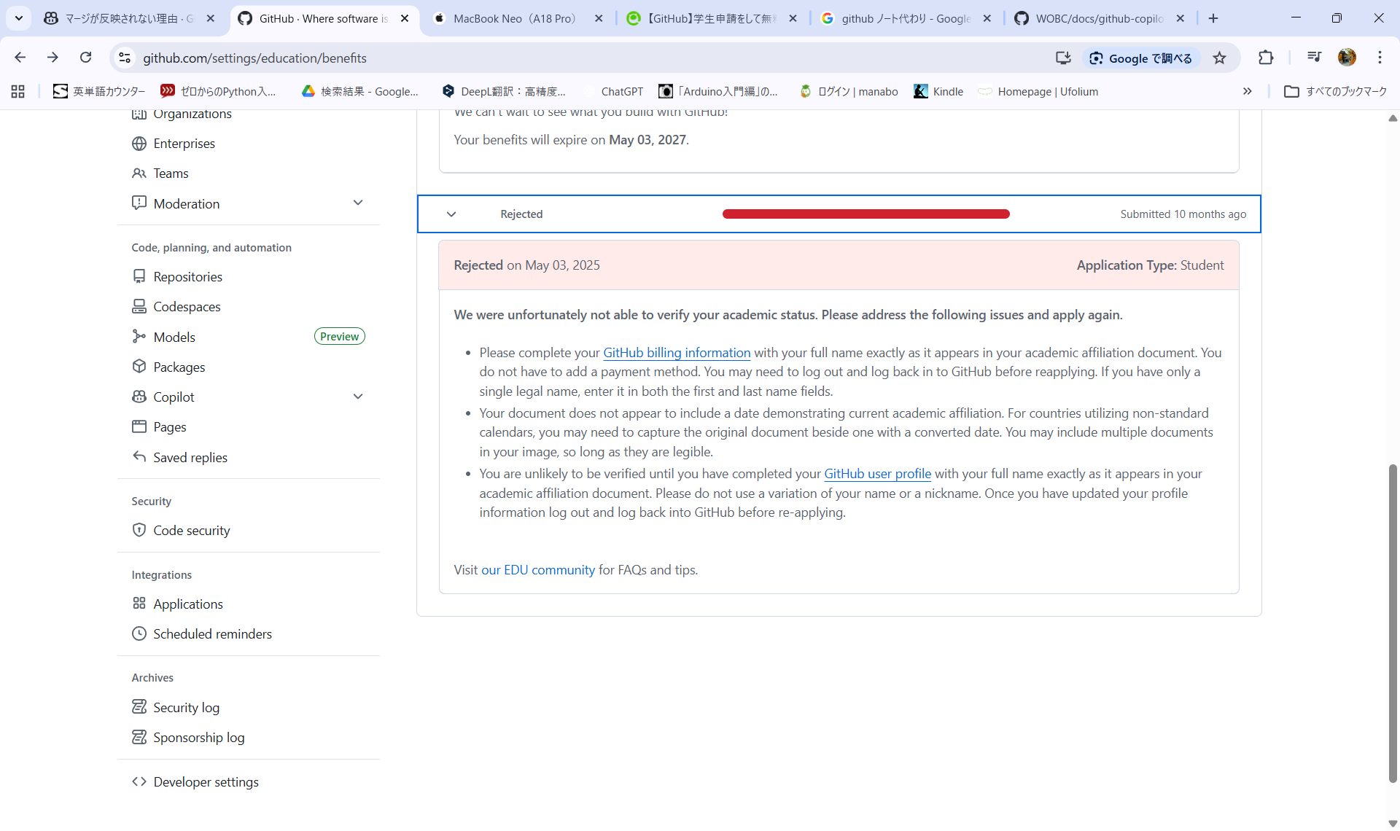
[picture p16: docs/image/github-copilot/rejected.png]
Rejected


### 補足

- メールアドレス入力時は手打ちではなくて、githubに登録されているメールアドレスから選択する形になります。なので事前にgithubのご自身のアカウントに学校のメールアドレスを登録してください。
- 申請却下時は、画像の見やすさや氏名・日付が確認できるかを見直して再申請

## 3. Copilot無料特典を有効化する

学生認証が通ったら、次にCopilotの無料特典を有効化（引き換え）するセットアップが必要です。

1. 審査完了のメールに記載されているリンク、もしくは [GitHub Educationの学習者ダッシュボード](https://education.github.com/learner/learn) にアクセスします。
2. 画面の案内に従って、Copilotのアクセス権（Student Developer Packの特典）を要求・セットアップする手続きを行います。

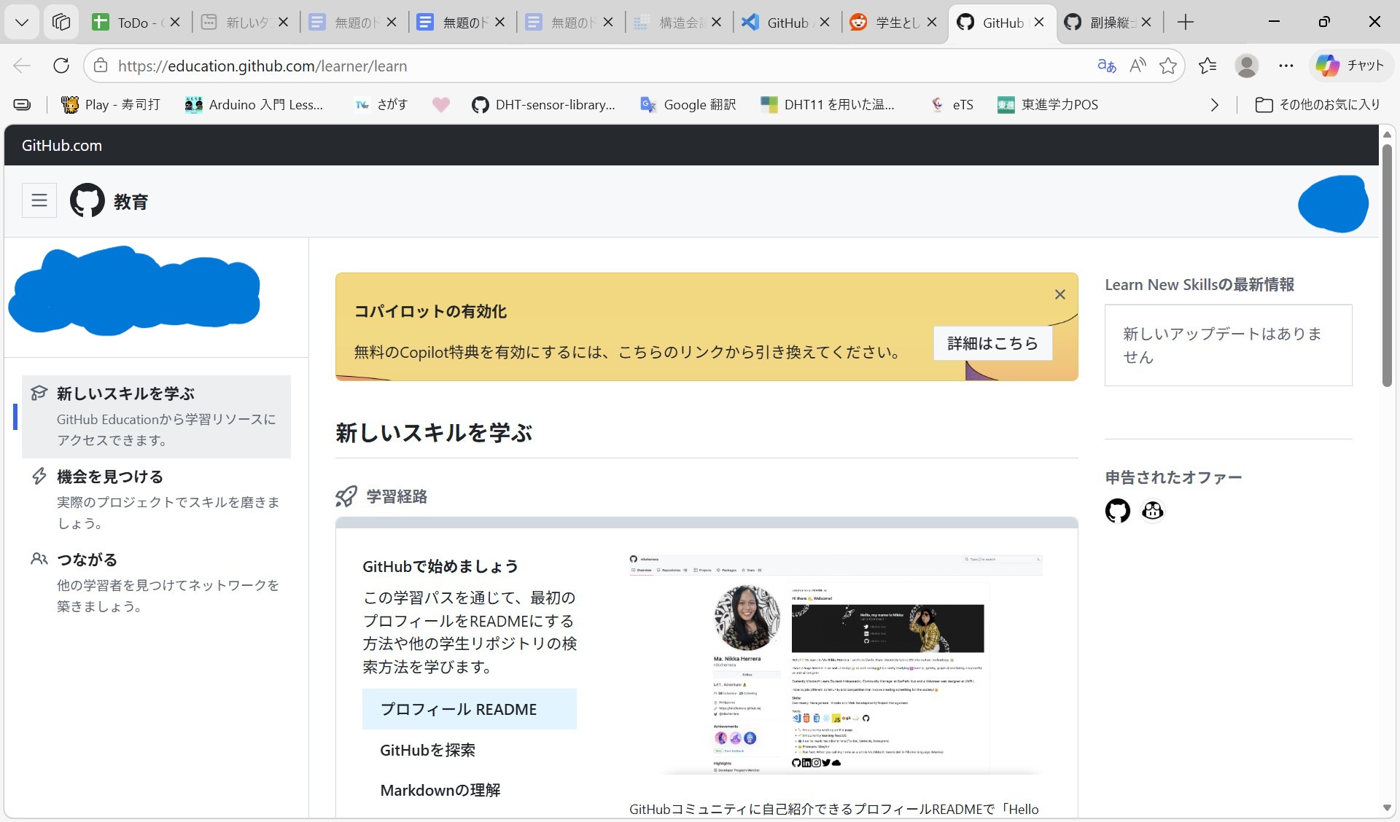
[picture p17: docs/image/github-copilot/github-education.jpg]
学習者ダッシュボード


3. 手続き完了後、GitHubの自分のアイコン -> `Settings` -> 左メニュー `Copilot` -> `Features` などを開き、有効になっているか確認します。

- このページで諸々の設定変更を行うことが出来ます。

> ここで料金表示が通常プランのままなら、Education認証反映待ちの可能性があります。
> 時間をおいて再確認してください。

## 4. VS CodeでCopilotを使えるようにする

1. VS Codeを開く
2. 拡張機能 `GitHub Copilot` と `GitHub Copilot Chat` をインストール
3. 対象リポジトリで補完が出るか確認

## 5. 動作確認（最小チェック）

1. Githubのweb版のchatを開く．[github.com/copilot](https://github.com/copilot)
2. `Agent`モードが使用できるか確認する．
3. VsCodeを開いて，同様に`Agent`モードが使えるか確認．

## 6. よくあるトラブル

### Q1. 学生認証が通らない

- 提出画像が不鮮明 / 情報不足のことが多い
- 学校名・所属・有効期限など確認しやすい資料に差し替える

### Q2. Education承認済みなのにCopilotが無料にならない

- 反映に時間がかかる場合あり
- GitHub Educationの学生者ダッシュボードから`Copilot Pro`の有効化のセットアップをまだ行っていない．
- GitHubから一度サインアウト→再ログイン
- `Settings` のプラン表示を再確認

### Q3. VS Codeで補完が出ない

- 拡張機能が有効か確認
- サインイン状態を確認
- 会社ネットワークやプロキシ環境で通信制限がないか確認

## 7. 更新ルール（この文書の運用）

- UI変更があったら、該当セクションのスクショや文言を更新
- 最終更新日を更新
- 「詰まったポイント」が出たらQ&Aへ追記

---

必要なら次回、以下も追加できます。

- 申請画面の実スクリーンショット付き手順
- 学内向け（新入生向け）1ページ版の簡易手順
- VS Code初期設定（推奨拡張・キーバインド）

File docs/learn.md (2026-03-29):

# WOBC/WCPP コード読解のための 学習プラン

最高です。では、**WOBC/WCPPのコード読解力を上げるための学習プラン**を、今のあなたの状況向けに作ります。  
（前提：平日30〜60分、休日1〜2時間）

これはチャッピーが作ってくれたものです．忠実に再現する必要はないと思います．あくまでご参考までに

---

## 全体方針（超重要）
毎週やることはこの3本柱です。

1. **C++基礎を強化**（本・小問題）
2. **WOBC実コードを読む**（main/component/library）
3. **小さい実験envで確認**（読む→触る→理解する）

> ゴールは「書ける人」より先に、**読んで説明できる人**になること。

---

## 1：地図づくり週間（全体像）
**目標**：WOBCの構造を言葉で説明できる。

- リポジトリをざっくり分解（`main.cpp`, `component`, `src/library`, `env`）
- `main.cpp`の処理フローを手書きで図にする
- `component`を1つ選び、  
  - 何をしているか  
  - いつ呼ばれるか  
  - 入出力は何か  
  をメモ

**毎日のミニタスク**
- 1日1関数だけ「日本語で3行要約」
- Copilotに「この関数の副作用は？」と聞いて検証

---

## 2：C++読解の土台固め
**目標**：WOBCでよく出るC++構文で止まらない。

重点：
- class/struct
- コンストラクタ
- 参照・ポインタ
- `const`
- ヘッダとcppの関係
- 名前空間

**実践**
- WOBC内で上記構文の実例を探してノート化
- 「このメンバ変数はどこで更新されるか」を追跡する練習

---

## 3：状態遷移と周期処理
**目標**：動作モードの流れを追えるようにする。

- mode/phase/stateに関係するコードを探す
- if/switchの分岐を状態遷移図にする
- 「この条件でどの処理に行くか」を表にする

**実験**
- 小さなenvでフラグ値を変えて分岐確認
- 期待した分岐になっているかログで確認

---

## 4：`src/library`攻略①（数学・ユーティリティ）
**目標**：libraryを“使える部品”として認識する。

- `src/library`から3ファイル選ぶ
- 各ファイルで以下を作る：
  - 提供関数一覧
  - 入出力
  - 前提条件
  - 使用例（最小コード）

**成果物**
- 自分用 `library_cheatsheet.md` を作成（超おすすめ）

---

## 5：`src/library`攻略②（I/O・通信・時刻系）
**目標**：わからないライブラリを単体で試せる。

- “難しめ”のライブラリを2つ選ぶ
- 依存関係を図にする（どのヘッダが必要か）
- 最小envで呼び出して動作確認

**ポイント**
- 動かなかった理由を必ず記録（依存不足、初期化不足など）

---

## 6：小規模改善を1つ通す
**目標**：読むだけでなく、理解に基づいた変更をする。

候補：
- コメント追加
- 命名改善
- ログ追加
- 小さなリファクタ（挙動不変）

**条件**
- 変更前後で挙動が同じことを説明
- 変更理由を日本語で書く（PRメモ風）

---

## 7：総復習＋説明力強化
**目標**：他人に説明できるレベルにする。

- main→component→libraryの流れを10分で説明する練習
- 「この機能はどこを見ればいいか」の索引を作る
- 過去7週間のメモを見て弱点を3つ抽出

**仕上げ課題**
- componentを1つ選び、  
  「目的 / 入力 / 出力 / 依存 / 典型バグ」を1枚にまとめる

---

## 週ごとのチェック基準（達成判定）
各週末に以下を自己採点（◎○△）：

1. 新しく理解した関数が5個以上あるか
2. libraryの使用例を1つ以上作ったか
3. 「わからない点」を言語化できたか
4. Copilotの回答を鵜呑みにせず検証したか

---

## Copilotの使い方テンプレ（そのまま使える）
- 「この関数の**入力・出力・副作用**を箇条書きで」
- 「この処理を**状態遷移**として説明して」
- 「このライブラリ関数の**最小使用例**をWOBC風に」
- 「このコードで起こりうる**バグ3つ**と再現条件は？」
- 「説明だけして。実装は書かないで」

---

## 1日の最小メニュー（忙しい日）
- 10分：1関数読む  
- 10分：メモ3行  
- 10分：Copilotに質問＋検証

これだけでも積み上がります。

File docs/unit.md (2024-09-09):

# ユニット一覧

# Tracker(a, 0x61)

# GS(d,e,f 0x64,0x65,0x66)

# Mission(b, 0x62)

# Rocket(c, 0x63)

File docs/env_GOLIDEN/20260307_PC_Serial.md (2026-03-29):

# src/library内のPC→WOBCのシリアル通信

作業者：NARROW

---

## 目標

アップリンクでコマンドを送るための前段階としてPCからLoRa基板になにか送って受け取るといった機能がどこに実装されていて，どういう機能でどういう使い方ができるのかを知りたかった．

---

## チャッピーとの会話

とりあえず，チャッピーに聞いてみた．以下会話のスクショ.

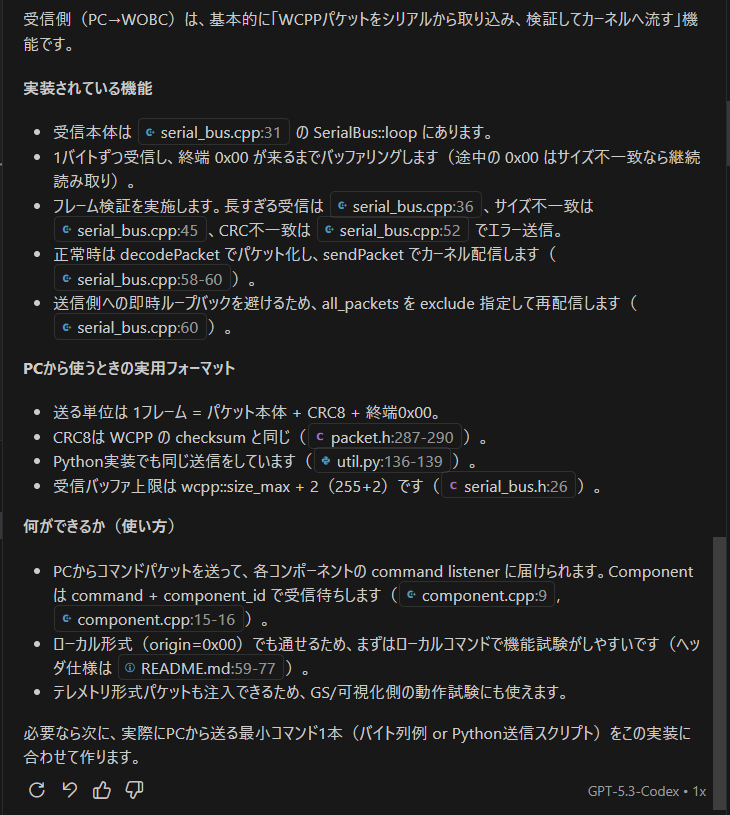
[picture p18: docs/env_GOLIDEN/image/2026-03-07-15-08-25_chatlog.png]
Chat Log


---

## チャッピー回答メモ（受信側: PC→WOBC）

受信側（PC→WOBC）は、基本的に「WCPPパケットをシリアルから取り込み、検証してカーネルへ流す」機能。

### 実装されている機能

- 受信本体は `src/library/core/serial_bus.cpp` の `SerialBus::loop()` にある。
- 1バイトずつ受信し、終端 `0x00` が来るまでバッファリングする（途中の `0x00` はサイズ不一致なら継続読み取り）。
- フレーム検証を実施する。
	- 長すぎる受信: `sbRL`
	- サイズ不一致: `sbSM`
	- CRC不一致: `sbCS`
- 正常時は `decodePacket()` でパケット化し、`sendPacket()` でカーネル配信する。
- 送信側への即時ループバックを避けるため、`all_packets` を `exclude` 指定して再配信する。

### PCから使うときの実用フォーマット

- 送る単位は 1フレーム = パケット本体 + CRC8 + 終端 `0x00`。
- CRC8 は WCPP の `checksum` と同じ（`wcpp::Packet::checksum`）。
- Python実装でも同じ送信をしている（`src/library/wcpp/python/util.py`）。
- 受信バッファ上限は `wcpp::size_max + 2`（255+2）。

### 何ができるか（使い方）

- PCからコマンドパケットを送って、各コンポーネントの command listener に届けられる。
- `Component` は command + `component_id` で受信待ちする実装。
- ローカル形式（`origin=0x00`）でも通せるため、まずはローカルコマンドで機能試験がしやすい。
- テレメトリ形式パケットも注入できるため、GS/可視化側の動作試験にも使える。

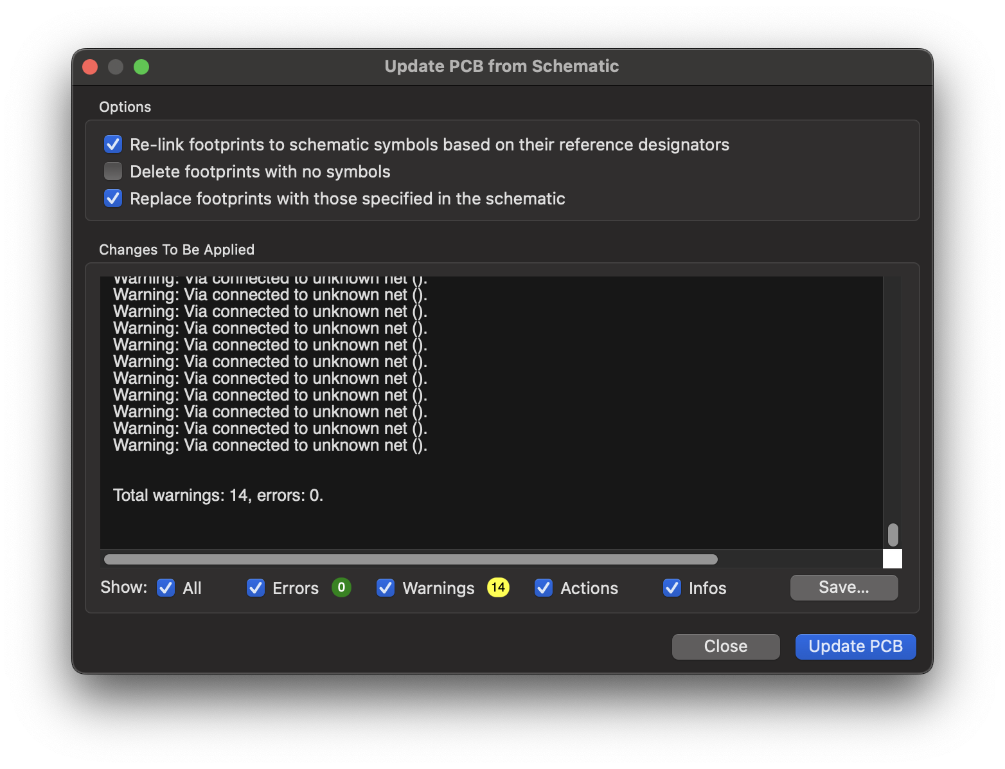
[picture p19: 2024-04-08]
docs/image/kicad/update_pcb.png

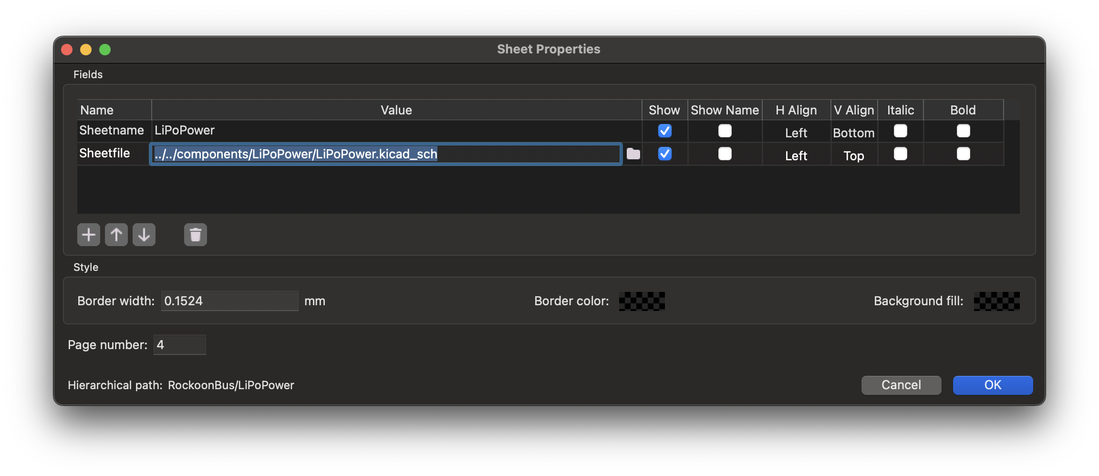
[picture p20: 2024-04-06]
docs/image/kicad/sheet_properties.png

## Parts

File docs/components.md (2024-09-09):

# コンポーネント一覧

# ESP32Core（0）
※ESP32CoreではなくMainコンポーネントのidが0

# RP2040Core (0)
※RP2040CoreではなくMainコンポーネントのidが0

# LiPoPower (1)

1セルのLiPoを充放電する．LiPo電圧不足時は，予備電源に切り替わる．

昇降圧コンバータで3.3V電源を作る．

LiPo，主電源，メイン3.3V系出力の電力を監視する．

LiPoの温度を監視し，ヒーターで一定温度を保つ．

- LiPo充放電コントローラ：MCP73871
- 電流センサ（LiPo, Vpp, Vdd）：INA226
- 予備電源切り替え回路
- 3.3V系出力 昇降圧コンバータ：TPS63070
- 外部サーミスタ温度計測
- 外部ヒーター駆動

## 内部IF

| ピン名 | 種別 | 内容 |
| --- | --- | --- |
| VBus | Power In | 充電用USBバスパワー（5V）|
| VPP | Power Out | 主電源（LiPoと予備電源を統合した電源系統） |
| Vdd\_BUS | Power Out | 外部モジュール駆動用電源（3.3V） |
| Vdd | Power Out | モジュール内駆動用電源（3.3V） |
| I2C\_SCL | I2C | INA226との通信用．ID: 0x4D (VPP)，0x4E (Vdd), 0x4F (LiPo) |
| I2C\_SDA | I2C | |
| CHAEGE\_IND | Digital In | 充電状態インジケータLED |
| PG | Digital Out (OC) | MCP73831 充電状態 |
| STAT1 | Digital Out (OC) | |
| STAT2 | Digital Out (OC) | |
| TEMP | Analog Out | サーミスタ出力．サーミスタに50uAの定電流を流したときの電圧を出力 |
| HEATER | Digital In | ヒーターON |
| BATTERY_V | Analog Out | 予備電源電圧．抵抗分圧4.7倍 |

## 外部IF

| 名前 | 種類 | 内容 |
| --- | --- | --- |
| Battery | XH 2pin | 予備電源入力（1: +, 2: -） |
| LiPo | PH 2pin | 1セル LiPo（1: +, 2: -）|
| Temp&Heater | PH 3pin | サーミスタとヒーター接続用（1: ヒーター+, 2: サーミスタ+, 3: ヒーター-・サーミスタ-） |
| Ext Switch | PH 2pin | 外部電源スイッチ接続用．ショートでON |
| Power Switch | スライドスイッチ | 電源スイッチ．外部電源スイッチとOR |
| PROG | VR | MCP73871 充電電流設定用可変抵抗 |
| USB Power | LED | USBバスパワー有効 |
| Backup Power | LED | 予備電源使用中 |
| Heater | LED | ヒーター駆動中 |
| VDD | LED | Vdd出力中 |
| Charge | LED | 充電状態 |

## テレメトリ

### 電源状態（P）

| エントリ名 | データ型 | 内容 |
| --- | --- | --- |
| Sc | enum | 電源ソース（0: LiPoまたはUSB，1: 予備電源）|
| Vb | int | 予備電源電圧(mV) |
| Vp | int | 主電源電圧(mV) |
| Ip | int | 主電源電流(mA) |
| Pp | int | 主電源電力(mW) |
| Wp | int | 主電源積算電力量(mWh) |
| Vd | int | Vdd電圧(mV) |
| Id | int | Vdd電流(mA) |
| Pd | int | Vdd電力(mW) |
| Wd | int | Vdd積算電力量(mWh) |

### LiPo状態（L）

| Cg | bool | 充電中 |
| --- | --- | --- |
| Vl | int | LiPo電圧(mV) |
| Il | int | LiPo電流(mA)，充電中は負の値 |
| Pl | int | LiPo電力(mW)，充電中は負の値 |
| Wl | int | LiPo積算放電電力量(mWh) |
| Dl | int | LiPo電池残量(%) |

### LiPo温度（H）

| エントリ名 | データ型 | 内容 |
| --- | --- | --- |
| Tm | float16 | 温度(℃) |
| Ht | int | ヒーター駆動Duty比(%) |

# LiPoPowerSimple (1)

1セルのLiPoを充放電する．乾電池を電源に使うこともできる（同時使用不可）．

昇降圧コンバータで3.3V電源を作る．

LiPoの電力を監視する．

- LiPo充放電コントローラ：MCP73871
- 電流センサ（LiPo）：INA226
- 3.3V系出力 昇降圧コンバータ：TPS63070

## 内部IF

| ピン名 | 種別 | 内容 |
| --- | --- | --- |
| VUSB | Power In | 充電用USBバスパワー（5V）|
| VDD | Power Out | 電源（3.3V） |
| I2C\_SCL | I2C | INA226との通信用．ID: 0x4F (LiPo) |
| I2C\_SDA | I2C | |
| CHAEGE\_IND | Digital In | 充電状態インジケータLED |
| PG | Digital Out (OC) | MCP73831 充電状態 |
| STAT1 | Digital Out (OC) | |
| STAT2 | Digital Out (OC) | |

## 外部IF

| 名前 | 種類 | 内容 |
| --- | --- | --- |
| Battery | XH 2pin | 予備電源入力（1: +, 2: -） |
| LiPo | PH 2pin | 1セル LiPo（1: +, 2: -）|
| Power Switch | スライドスイッチ | 電源スイッチ |
| PROG | VR | MCP73871 充電電流設定用可変抵抗 |
| USB Power | LED | USBバスパワー有効 |
| VDD | LED | Vdd出力中 |
| Charge | LED | 充電状態 |

## テレメトリ

### LiPo状態（L）

| Cg | bool | 充電中 |
| Vl | int | LiPo電圧(mV) |
| Il | int | LiPo電流(mA)，充電中は負の値 |
| Pl | int | LiPo電力(mW)，充電中は負の値 |
| Wl | int | LiPo積算放電電力量(mWh) |
| Dl | int | LiPo電池残量(%) |

# ModuleIF (3~10)

他モジュールと接続し，電源を供給する．親側にのみ用いる．

- モジュール間コネクタ：4pin Grove
- 電流センサ：INA226
- ロードスイッチ：TCK106AF

## 内部IF

| ピン名 | 種別 | 内容 |
| --- | --- | --- |
| VIN | Power In | 駆動用電源（3.3V） |
| EN | Digital In | ロードスイッチON |
| I2C\_SCL | I2C | INA226との通信用．ID: 0x48~0x4Bを選択 |
| I2C\_SDA | I2C | |

## 外部IF

| 名前 | 種類 | 内容 |
| --- | --- | --- |
| Jumper | 1.27mm ジャンパピン | ショート時 CAN終端抵抗有効 |
| Power | LED | 電源出力インジーケータ |

## テレメトリ

### 電源状態（P）

| エントリ名 | データ型 | 内容 |
| --- | --- | --- |
| On | bool | 電源出力ON/OFF |
| Vo | int | 出力電圧(mV) |
| Io | int | 出力電流(mA) |
| Po | int | 出力電力(mW) |
| Wo | int | 積算出力電力量(mWh) |

## コマンド

### 電源ON/OFF (P)

| エントリ名 | データ型 | 内容 |
| --- | --- | --- |
| On | bool | 電源出力ON/OFF |

# ModuleIFSimple (-)

他モジュールと接続する．親側・子側どちらにも用いる．
ModuleIFと異なり，電源ON/OFFや電力測定機能はない．

- モジュール間コネクタ：4pin Grove

## 外部IF

| 名前 | 種類 | 内容 |
| --- | --- | --- |
| Jumper | 1.27mm ジャンパピン | ショート時 CAN終端抵抗有効 |

# LoRa (11~18)

# Logger (20)

RTCにより絶対時刻を提供する．
Micro SDカードにタイムスタンプ付きでログを記録する．

- Micro SDカードコネクタ
- RTC：PCF8563

## 内部IF

| ピン名 | 種別 | 内容 |
| --- | --- | --- |
| +BATT | Power In | RTCバックアップ用電源 3V |
| I2C\_SCL | I2C | RTCとの通信用．ID: 0x51 |
| I2C\_SDA | I2C | |
| SD\_CLK | SPI | SDカード通信用 |
| SD\_MOSI | SPI | |
| SD\_MISO | SPI | |
| SD\_SS | SPI | |
| SD\_DET | Digital Out (OC) | SDカード挿入検出 |

## 外部IF

| 名前 | 種類 | 内容 |
| --- | --- | --- |
| Power | LED | 電源出力インジーケータ |
| Jumper | 1.27mm ジャンパピン | ショート時 CAN終端抵抗有効 |

## テレメトリ

### 絶対時刻 (T)

| エントリ名 | データ型 | 内容 |
| --- | --- | --- |
| Ut | int | UNIX時間 UTC（ms）．日本時間にするには+9h |
| Ts | int | 起動からの経過時間（ms） |

## コマンド

### 絶対時刻セット (T)

| エントリ名 | データ型 | 内容 |
| --- | --- | --- |
| Ut | int | UNIX時間 UTC（ms）．|

# GPS

## GPSActive (21)

### 位置情報(M)
| エントリ名 | データ型 | 内容 |
| --- | --- | --- |
|LA|double|緯度(°)|
|LO|double|経度(°)|
|AL|int|GPS高度(m)|
|UT|int|Unix時間|

## GPSPassive (23)

### 位置情報(M)
| エントリ名 | データ型 | 内容 |
| --- | --- | --- |
|LA|double|緯度(°)|
|LO|double|経度(°)|
|AL|int|GPS高度(m)|
|UT|int|Unix時間|

# Pressure (25)

## 環境情報(E)
| エントリ名 | データ型 | 内容 |
| --- | --- | --- |
|PR|int|絶対気圧(hPa)|
|TE|int|温度(℃)|
|HU|int|湿度(％)|
|PA|int|気圧高度(m)|

# IMU (30)
## 姿勢情報(D)
| エントリ名 | データ型 | 内容 |
| --- | --- | --- |
|Ax|float32|x方向加速度(m/s^2)|
|Ay|float32|y方向加速度(m/s^2)|
|Az|float32|z方向加速度(m/s^2)|
|Gx|float32|x軸周り角速度(deg/s)|
|Gy|float32|y軸周り角速度(deg/s)|
|Gz|float32|z軸周り角速度(deg/s)|
|Mx|float32|x方向時速密度(G)|
|My|float32|y方向時速密度(G)|
|Mz|float32|z方向時速密度(G)|
|PH|int|方角(°)|
|SI|int|仰角(°)|

# LCD (35)

# Ignite (36)

# RCS (37)

# TankPressure (40)

## タンク状況
| エントリ名 | データ型 | 内容 |
| --- | --- | --- |
|TP|int|タンク内圧力(kPa)|
|NP|int|スラスタ圧力(kPa)|
|TT|int|タンク温度(℃)|

# HX711 (45)

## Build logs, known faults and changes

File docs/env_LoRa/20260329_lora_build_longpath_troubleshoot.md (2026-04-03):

# LoRa build失敗時の復旧手順（Windows長パス問題）

作業者：sands

---

## 目標

`env:LoRa` の build が通らないときに、
原因の切り分けと復旧を同じ手順で再実行できるようにする。

---

## 事象

`env:LoRa` の build 実行時に、`env:rp2040` 側の依存（`framework-arduinopico`）取得で停止することがある。

主な要因:

- Windows のパス長制限に引っかかる
- `.platformio` キャッシュ破損や中途半端な展開が残っている

`env:LoRa` は `env:rp2040` を継承しているため、LoRa単体の問題に見えても RP2040 依存取得で失敗する。

---

## 復旧コマンド（PowerShell）

作業ディレクトリへ移動:

```powershell
cd C:\Users\sands\WOBC
```

`sands` は自分のユーザー名に置き換える。

1. Windows 長パスを有効化

```powershell
git config --global core.longpaths true
```
```powershell
git config --global --get core.longpaths
```
> ここで`true`と返ってくれば大丈夫

2. 失敗しやすい依存キャッシュを削除

```powershell
Remove-Item -Recurse -Force "$env:USERPROFILE\.platformio\packages\framework-arduinopico" -ErrorAction SilentlyContinue
```
```powershell
Remove-Item -Recurse -Force "$env:USERPROFILE\.platformio\.cache" -ErrorAction SilentlyContinue
```
```powershell
Remove-Item -Recurse -Force ".\.pio" -ErrorAction SilentlyContinue
```

3. 削除確認

```powershell
Test-Path "$env:USERPROFILE\.platformio\packages\framework-arduinopico"
```
```powershell
Test-Path "$env:USERPROFILE\.platformio\.cache"
```
```powershell
Get-ChildItem "$env:USERPROFILE\.platformio\.cache" -Force
```

4. build 再実行

コマンドでやる必要は全くないので，VSCode上でまずbuildしてみてください．

```powershell
C:\Users\sands\.platformio\penv\Scripts\platformio.exe run --environment LoRa
```

必要なら詳細ログで再実行:

```powershell
C:\Users\sands\.platformio\penv\Scripts\platformio.exe run --environment LoRa -j 1 -v
```

---

## 判定の目安

- `git config --global --get core.longpaths` が `true` を返す
- `platformio run --environment LoRa` が `SUCCESS` で完了する

補足:

- `.platformio\.cache` は削除後に `downloads` や `tmp` が再作成される場合がある（正常）

---

## 再発時の確認ポイント

- 別PCで Git の長パス設定が未実施ではないか
- セキュリティソフトやプロキシで Git 取得が失敗していないか
- `platformio.ini` の `env:LoRa` が継承している `env:rp2040` の依存取得に失敗していないか

---

## 参考

- `docs/env_GOLIDEN/20260307_lora_build_troubleshoot.md`

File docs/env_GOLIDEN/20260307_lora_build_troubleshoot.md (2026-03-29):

# LoRa build失敗の調査と対応（別PC向け）

作業者：narrow

---

## 目標

別PCで `LoRa` 環境のbuildが通らない事象について、
「バージョンを変更せず」に原因候補を整理し、再現しやすい対処手順を作る。

---

## 発生していた事象

別PCで以下のようなエラーが発生して `LoRa` buildが失敗。

- `Failed to recurse into submodule path 'pico-sdk/lib/tinyusb'`
- `Could not process command ['git', 'submodule', 'update', '--init', '--recursive', '--force']`

`LoRa` はRP2040系（arduino-pico）を使うため、依存取得時にサブモジュール展開で失敗するとbuild不可になる。

---

## 原因候補（今回の整理）

バージョン差分以外で、主に次の4点を典型要因として整理。

1. ネットワーク / プロキシ制限
2. Git取得の途中失敗（再帰submodule展開失敗）
3. `.platformio` キャッシュ破損
4. Windows長パス設定不足

---

## 実施したこと

### 1) 設定確認

- `platformio.ini` の `env:LoRa` が `env:rp2040` を継承していることを確認
- `framework-arduinopico` をGitHubから取得する構成であることを確認

### 2) 依存URLの最小修正（バージョン固定のまま）

SSH形式の依存URLをHTTPS形式へ置換する方針を実施。

- 変更方針：`git@github.com:...` → `https://github.com/...`
- 目的：別PCでSSH鍵が未設定でも依存取得できるようにする

### 3) build確認

- `platformio run --environment LoRa` を実行して、依存解決とbuild進行を確認

---

## 現時点の設定メモ

現在の `platformio.ini` 上では、`can2040` はHTTPS指定になっていることを確認。

- `https://github.com/KevinOConnor/can2040.git`

※ `can_common` / `esp32_can` は現時点ではSSH形式が残っているため、
別PCでESP32系環境を使う場合は同様にHTTPS化すると詰まりを減らせる。

---

## 別PCでの推奨復旧手順（バージョン変更なし）

PowerShellで以下を順番に実施。

1. `git config --global core.longpaths true`
2. `Remove-Item -Recurse -Force "$env:USERPROFILE\.platformio\packages\framework-arduinopico" -ErrorAction SilentlyContinue`
3. `Remove-Item -Recurse -Force "$env:USERPROFILE\.platformio\.cache" -ErrorAction SilentlyContinue`
4. `C:/Users/<username>/.platformio/penv/Scripts/platformio.exe run --environment LoRa -j 1 -v`

プロキシ環境の場合は、`git config --global -l` で `http.proxy` / `https.proxy` の誤設定も確認する。

---

## まとめ

- 今回は「バージョン変更なし」で、環境要因の切り分けと対処に絞って対応した。
- 失敗ログ上の主因は、RP2040依存取得時のsubmodule再帰展開失敗の可能性が高い。
- HTTPS依存化 + 長パス有効化 + キャッシュ再取得の組み合わせで、別PCの再現失敗を減らせる見込み。

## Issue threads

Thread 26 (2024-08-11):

ブランチ整理

KeisukeSuganuma, 2024-08-11:
発注基板の作成が終わったのでブランチの整理をします。

@fujiy
- developのブランチは、コンフリクトを解消してすべてmainにマージ、その後削除
- featureはIGNとRocketはまだ完了していないため、そのまま作業
- featureのMissionCore、Tracker、GS、RCSは発注基板作成まで終わったので、プルリク出してmainにマージ
- コンポーネントの一部が修正必要(共通部品)なため、新たにfeature/componentブランチをmainから作り、修正

という作業でよろしいですか？featureのブランチは削除せずに残しておくのか、それとも一度削除して作りなおすのかどちらがよろしいですか？

@nassan88
develop/nasuとfeature/Trackerのブランチがコンフリクト起こしてるっぽいので確認してみて

fujiy, 2024-08-11:
OK
feature/　はこまめに作って，mergeし終わって不要になれば削除してもいいと思う

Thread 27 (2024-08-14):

Platform IOの使い方について

KeisukeSuganuma, 2024-08-14:
WOBCのmainをvs cordのplatform ioで開いて適当なプログラムをbuildしようとしてもうまくいかない。

考えられる問題点

- 画面下部に表示されるはずのツールバーが現れないため、environmentの切り替え方法がわからない（おそらく自分の環境特有の問題）
- どうやらBuildするときに開いていたファイルに関係なくESP32Coreのbuildが行われてしまい、実行したいプログラムのbuildが行えていない
- inoファイルは.cppに直さないといけない？

@fujiy どのようにbuildしているか参考に教えていただけませんか？

fujiy, 2024-08-14:
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
ここにenvironment一覧が出ない？ここで全部buildも一部build, uploadもできるはず

moduleを追加するときは，platformio.iniで[env:ESP32CoreTest]を複製して，名前とbuild_source_filterを書き換える

あと.inoじゃなくてmain.cppにしないといけない

fujiy, 2024-08-23:
初回ビルドは諸々のダウンロードで時間かかるとは思う
mainブランチだとe220.cppがいろんなところにあるせいでmultiple definitionのエラーが出るね
そっちはどういうエラー？

KeisukeSuganuma, 2024-08-23:
すみません、こちらのせいですね...申し訳ないです。
ちょっと今思い当たる節があって、実際のmainのブランチ以外のファイルがローカルの方に残ってまして(表現が適切かわからないのですが、本来ないはずのwccpという名前のフォルダがあったりします)、その中でno such file的なこと言われてる状況です。mainを完全に再現するにはクローン等の操作をすればいいんですかね？
一度zipでダウンロードして試してみようと思います

fujiy, 2024-08-23:
untracked fileを削除すれば消えるね
あとwcppはgit submoduleだから明示的な操作がいる
https://dqn.sakusakutto.jp/2013/06/git_submodule_empty_directory.html

KeisukeSuganuma, 2024-08-24:
こういうエラーが出たんですけど、対処法が良くわかんないです...。
collect2.exe: error: ld returned 1 exit status
*** [.pio\build\Esp32CoreTest\firmware.elf] Error 1

KeisukeSuganuma, 2024-08-24:
> untracked fileを削除すれば消えるね あとwcppはgit submoduleだから明示的な操作がいる https://dqn.sakusakutto.jp/2013/06/git_submodule_empty_directory.html

こちらを試していなかったので帰宅後やってみます。
操作としては
cd ~/wobc
git submodule init
git submodule update
をGit Bashで打てばいいということですかね？

fujiy, 2024-08-24:
のはず
エラーはそれで全部？

KeisukeSuganuma, 2024-08-24:
ESP32CoreTestの方はそれで全部だと思います。警告で真っ黄色でしたけど。RP2040CoreTestはダウンロードに時間かかりすぎてエラーが出てるかすらわかってないです。

fujiy, 2024-08-24:
黄色のところにエラーもあるはずだから全部貼ってほしい

KeisukeSuganuma, 2024-08-24:
ESP32CoreTestの方はこのような感じです。あまりに長いので色付きで分かる画像と、文章をzipにまとめて貼ります。
RP2040は色々インストールした後にこれで終わっていてbuildできてるのかよくわからないです(画像)

[ESP32CoreTest_Comp.zip](https://github.com/user-attachments/files/16735934/ESP32CoreTest_Comp.zip)

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

fujiy, 2024-08-24:
https://community.platformio.org/t/cannot-open-map-file/35729

KeisukeSuganuma, 2024-08-24:
すみませんC直下に入れたらEspの方はビルドできました...RP2040は今やってます
申し訳ないです...
黄色い警告は相変わらず出るようですが共有した方が良いですか？

KeisukeSuganuma, 2024-08-24:
一方でRP2040の方はエラー吐きます...履歴を見るとこの辺がエラーになっている部分でした。最後一行のみ赤字になっている状態です。

**error: unable to create file Application/8_uarts_server/RT-Thread/uart_server_rtt/rt-thread/components/vmm/linux_patch-v3.8/0001-RTT-VMM-implement-dual-system-running-on-realview-pb.patch: Filename too long
error: unable to create file Application/8_uarts_server/RT-Thread/uart_server_rtt/rt-thread/components/vmm/linux_patch-v3.8/0002-arm-gic-correct-the-cpu-map-on-gic_raise_softirq-for.patch: Filename too long**
**fatal: Unable to checkout '17761f5cf9dbbf2dcf665b7c04934188add20082' in submodule path 'pico-sdk/lib/tinyusb/hw/mcu/wch/ch32v307'**
Submodule path 'pico-sdk/lib/tinyusb/lib/CMSIS_5': checked out '20285262657d1b482d132d20d755c8c330d55c1f'
Submodule path 'pico-sdk/lib/tinyusb/lib/FreeRTOS-Kernel': checked out '2a604f4a2818b8354b5e1a39e388eb5e16cfbc1f'
Submodule path 'pico-sdk/lib/tinyusb/lib/lwip': checked out '159e31b689577dbf69cf0683bbaffbd71fa5ee10'
Submodule path 'pico-sdk/lib/tinyusb/lib/sct_neopixel': checked out 'e73e04ca63495672d955f9268e003cffe168fcd8'
Submodule path 'pico-sdk/lib/tinyusb/tools/uf2': checked out '19615407727073e36d81bf239c52108ba92e7660'
Submodule 'hidapi' (https://github.com/signal11/hidapi) registered for path 'pico-sdk/lib/tinyusb/tools/uf2/hidapi'
Cloning into 'C:/Users/gacch/.platformio/.cache/tmp/pkg-installing-ure6reax/pico-sdk/lib/tinyusb/tools/uf2/hidapi'...
Submodule path 'pico-sdk/lib/tinyusb/tools/uf2/hidapi': checked out 'a6a622ffb680c55da0de787ff93b80280498330f'
**fatal: Failed to recurse into submodule path 'pico-sdk/lib/tinyusb'
fatal: Failed to recurse into submodule path 'pico-sdk'**
Submodule path 'tools/libbearssl/bearssl': checked out 'f294aa022f82833941ffdf3b0f306c2072e3a26c'
Submodule path 'tools/pyserial': checked out '0e7634747568547b8a7f9fd0c48ed74f16af4b23'

**VCSBaseException: VCS: Could not process command ['git', 'submodule', 'update', '--init', '--recursive', '--force']**

KeisukeSuganuma, 2024-08-24:
そのうえ数行も添付しておきます。流れがかわったのがこの辺からです

Submodule path 'pico-sdk/lib/tinyusb/hw/mcu/st/stm32l5xx_hal_driver': checked out '675c32a75df37f39d50d61f51cb0dcf53f07e1cb'
remote: Enumerating objects: 327, done.
remote: Counting objects: 100% (327/327), done.
remote: Compressing objects: 100% (13/13), done.
remote: Total 170 (delta 156), reused 170 (delta 156), pack-reused 0 (from 0)
Receiving objects: 100% (170/170), 179.68 KiB | 351.00 KiB/s, done.
Resolving deltas: 100% (156/156), completed with 154 local objects.
From https://github.com/STMicroelectronics/stm32u5xx_hal_driver
 * branch            2e1d4cdb386e33391cb261dfff4fefa92e4aa35a -> FETCH_HEAD
Submodule path 'pico-sdk/lib/tinyusb/hw/mcu/st/stm32u5xx_hal_driver': checked out '2e1d4cdb386e33391cb261dfff4fefa92e4aa35a'
Submodule path 'pico-sdk/lib/tinyusb/hw/mcu/st/stm32wbxx_hal_driver': checked out '2c5f06638be516c1b772f768456ba637f077bac8'
Submodule path 'pico-sdk/lib/tinyusb/hw/mcu/ti': checked out '143ed6cc20a7615d042b03b21e070197d473e6e5'

fujiy, 2024-08-24:
https://myscreate.com/filename-too-long/

KeisukeSuganuma, 2024-08-24:
できました！ご迷惑をおかけしました。

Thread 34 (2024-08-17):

LoRaの通信方法について

KeisukeSuganuma, 2024-08-17:
@fujiy
通信試験で発覚したのですが、10バイト程度のデータ量で5秒ほど間隔を設けているにも関わらず、しばらく通信を行うとバッファオーバーフローを起こしているかのような症状が見られます。
症状を下記に載せますが、これがバッファオーバーフローなのかどうか。もしそうであれば昨年はどのようなフロー制御を行っていたか教えていただけますか？

症状：
しばらくは安定して通信を行うことができるが、突如感度が-1になり、それ以降の受信が止まる。
長時間経過後、239バイトほどのデータ（繰り返し）がまとめて表示され、それ以降10バイトよりも小さい範囲で受信が行われる。
このとき、受信感度は-250程度になる。
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

fujiy, 2024-08-17:
シリアル通信で受け取ったデータが化けてるか何かで，先頭のデータ長の読み取りを間違ってる雰囲気があるな
これどのコード使ってる？

KeisukeSuganuma, 2024-08-17:
mainにあがってるsrc/compornent/RFtestの中にあるコードです。チャンネルだったりは多少変えてますけど基本的にはそのプログラムと同じです。

fujiy, 2024-08-17:
なるほど
LoRaモジュールを使ってると思うけど，Trackerでも再現する？

KeisukeSuganuma, 2024-08-17:
今Tracker→GS/LoRaで通信試験実施しているので、そういう意味ではすでに再現しています。

fujiy, 2024-08-17:
Trackerで受信するとどうなる？
10バイト送信じゃなくて100バイトとか長めに送ったら途中で化ける？

KeisukeSuganuma, 2024-08-17:
帰宅後試してみます。
かなり時間かかります、申し訳ないです

fujiy, 2024-08-17:
長距離通信できなかったのはこれが原因？

KeisukeSuganuma, 2024-08-17:
それが、非常に申し訳ないんですけど、アンテナのスイッチが逆でして、HIGHとLOW逆にしたら回復しました。
ただ一点、3.3Vって推奨供給電圧より低いようで、低出力っぽいんですよね。ここをどうしようか迷ってます。(昇圧するか、他のICが大丈夫なら3.5Vまで上げるか)
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

fujiy, 2024-08-17:
まじか　知らなかった
確認する必要はあるけど，大体のicが3.6Vくらいまでならいけると思うから若干上げるのはアリ

KeisukeSuganuma, 2024-08-17:
私も今日見つけたのですが
https://support.dragon-torch.tech/about_e220-900t22sjp_link
こちらに色々と初耳情報のっていたので、他に気にしなくてはならない事があれば教えて頂けると幸いです

KeisukeSuganuma, 2024-08-17:
Tracker→Trackerで試験を行った結果
10バイト、5秒間隔：10分ほど実施するも不具合起こらず
100バイト、5秒間隔：10分ほど実施するも不具合起こらず
でした。どうやらLoRaモジュール固有の問題のようです。どうすればいいんですかね...

fujiy, 2024-08-17:
rp2040のSerial通信がまた怪しそう
LoRaモジュールで100バイト受信はどうなる？
あるいはボーレート変えてみるとか

KeisukeSuganuma, 2024-08-17:
LoRaで100バイト受信では10分ほど継続しても不具合を起こしませんでした...そういうものですか...？
受信側のボーレートを9800にしたところ、最初に提示した不具合が生じました。10バイトでのみ発生するのかどうかわかりませんが、原因がよくわかんないです。送信側のボーレートも変えますか？

fujiy, 2024-08-17:
送信はTrackerだよね？そっちは（たぶん）正しく動いてるんだよね

https://github.com/wasa-rockoon/WOBC/issues/34#issue-2471430299

fujiy, 2024-08-17:
- SoftwareSerialの問題か，e220.cppにバグがあるか．E220の出力を直接見たら正しいか？

KeisukeSuganuma, 2024-08-17:
送信はそうですTrackerです。
簡単なものから試してみようと思います。

KeisukeSuganuma, 2024-08-17:
10バイトの送信
受信のE220：57600+シリアル57600→毎回100～200バイトほど貯めて送信される
受信のE220：9800+シリアル9600→最初の不具合のまま

fujiy, 2024-08-17:
あとはlora1 lora2 どちらでも同じ症状が出る？ それとlora2_serialを消してSerialPIOを一つだけにしたらどうなるか

fujiy, 2024-08-18:
応急処置としてタイムアウトを追加して，化けたデータがそれ以降に影響しないようにしてみた

https://github.com/wasa-rockoon/WOBC/blob/8493cb1238e4e91704cc1b57d417f8103d53274e/src/components/LoRa/e220.cpp

KeisukeSuganuma, 2024-08-18:
タイムアウト有効に働きました！一度感度-1になっても復帰できていそうです。本番もこのようにして対策しますか？
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

fujiy, 2024-08-18:
そうだね，できれば元の原因をなんとかしたいところではあるけど優先順位次第かな

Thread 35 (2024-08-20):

電池選定(Tracker)

KeisukeSuganuma, 2024-08-20:
Trackerの電力消費をINAとSDカードを使って取得したところ、添付画像のようになりました。
おおよそ500mWとして、3.7Vで割った136mAに想定稼働時間5時間をかけて680mAhがマストになると思います。
LoRaの送信頻度にもよりますが、1200mAh+Backupくらいが重量的に見てもいいバランスかなとと思います。
ただ、低温時の電圧低下等の考え方がいまいちわからないので、ご意見うかがえないでしょうか？
DTP673450(PHR)とかにしようかなと考えております。

バックアップは使用実績のあるFR6HJ/4Bを4本ですかね。

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

KeisukeSuganuma, 2024-08-20:
Mission側は同様の消費電力136mA×2=272mAを準備～発射想定時間2時間持たせて544mAh。
それに136mAを3時間持たせるために408mAhを足して、さらにスラスタ駆動用に余分を見ても2000mAhで足りるかなと思っています(軽量化のためにスラスタ駆動用とメイン駆動用は同一電源にすることになりました)
DTP605068(PHR)になりそうです。

rocketには大きさの制約があるので、φ35におさまるサイズの上限がDTP603450(PHR)のようなので1000mAhまでは積むことができそうです。
この場合、発射後4,5時間は持ちそうですがサイズ的に収まるかよくわからないので寸法確認してきます。

KeisukeSuganuma, 2024-08-20:
@nassan88 点火用の電源はどうする？

fujiy, 2024-08-20:
低温時どうなるかは正直よく分からないなあ，基本的には容器（とヒーター）で保温する前提で考えたほうが楽そう
バックアップ電池はDCDCで昇圧されるから，最低２本あれば十分ではあると思う

KeisukeSuganuma, 2024-08-20:
なるほど、それはかなりありがたいです。
重量きつめなので2本で検討してみます。
ありがとうございます
計算方法等はあってますか？

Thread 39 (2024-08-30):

RCSモジュール　GPIO18,19の出力が低い

KeisukeSuganuma, 2024-08-30:
RCSモジュールの動作確認中に電磁弁のスイッチであるピンの出力電圧が低いことがわかりました。
色々試してみましたが、RP2040の故障ではないかと思っています。
後日学生会館に置いてきた予備基板を用いて再確認を行うつもりですが、その前にこの回路で出力が下がる要因があるかお尋ねしたいです。
ちなみに出力電圧は他のピンであれば3.3V出ており、18,19ピンのみ0.6V程度しか出ません。他のモジュール(Controllerモジュール)で同じプログラムを書き込んだら3.3V出ています。ONOFFは切り替えられるようで、0V⇄0.6Vの切り替えは可能です。

何か心当たりがあれば教えて下さい！
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

KeisukeSuganuma, 2024-08-30:
すみません画像が切れていますがこの下部は3本ともすべてGNDにつながっています

fujiy, 2024-08-30:
うーん
電磁弁の電源をONしない場合でも同じく0.6Vが出る？

KeisukeSuganuma, 2024-08-30:
すみません、説明不足でした。
電磁弁が手元にないので今電磁弁はつながっていません。
NMOSのドレインは浮いている状態です。

fujiy, 2024-08-30:
なるほど
電磁弁は一度も繋いだことない？

KeisukeSuganuma, 2024-08-30:
今のところ一度もないです。

fujiy, 2024-08-30:
基板データを見てみたんだけど，valve1とvalve2の途中にGNDのビアが刺さってない？

KeisukeSuganuma, 2024-08-30:
刺さってます？発注基板はMissionOrderFileなのでそっちの方は大丈夫だと思いますけど...
テスターで導通チェックしてみましたが特につながってはなさそうです。

fujiy, 2024-08-30:
確かにそっちは大丈夫だな
一応プログラム見せてもらえる？

KeisukeSuganuma, 2024-08-30:
大した量ではないのでここに直接貼ってしまいますね。
ほんとに簡単なものなんですけど、確認お願いします。

#include <Arduino.h>

void setup() {
  pinMode(18, OUTPUT);
  pinMode(19, OUTPUT);

  digitalWrite(18, HIGH);
  digitalWrite(19, HIGH);
}

void loop() {
  // put your main code here, to run repeatedly:
  digitalWrite(18, HIGH);
  digitalWrite(19, HIGH);
  delay(3000);
  digitalWrite(18, LOW);
  digitalWrite(19, LOW);
  delay(3000);
}

fujiy, 2024-08-30:
うーんわからないなあ
どこかとショートしてるくらいしか思いつかないな

今回のとは関係ないけど，電磁弁に並行にフリーホイールダイオードを追加しないと逆起電力で回路壊れるかも

KeisukeSuganuma, 2024-08-30:
なるほど、配線作業のときに繋げます。

ショートですか...見たところ見つからないですねー...もう一個の基板で試してみる他なさそうですね

KeisukeSuganuma, 2024-08-31:
NMOSの向き間違えでした。
なんとか修正可能です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

Closed 2024-09-01.

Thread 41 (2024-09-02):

カーネル解読

KeisukeSuganuma, 2024-09-02:
まだカーネルの使い方が理解できておらず解読作業中です。全く読み切ることができてませんがちょっとずつ分かってきたので確認も兼ねて質問させていただきたいです。

まず、module_idとunit_idの設定ですがpreferenceを使って不揮発メモリに保存しておくという解釈であってますか？もしあっているなら、不揮発メモリへの保存は実際に書き込むmodulename/main.cppのファイルではないもので設定するのでしょうか。TBDと書いてあったので、その設定を早いうちにしておく必要があるんですかね？

fujiy, 2024-09-02:
https://github.com/wasa-rockoon/WOBC/blob/aa941c142f3019fef4b720576778969fe941e1ff/src/modules/GS/main.cpp#L46
この辺りのことだと思うけど，
unit_idもmodule_idもこんな感じでコード上で指定する．
ただしmodule_idに関しては，間違ったプログラムを書き込んだときに止められるように，EEPROMに指定したmodule_idを保存しておいて今回の値と比較する機能がkernelに入ってる．module_idが一致しないときは`kernel::begin`がfalseを返す．
EEPROMの書き込みをユーザー側でする必要は特にない．（というか他で何らかの値を保存したいときは，EEPROMやESP32のPreferenceを直接触らず https://github.com/wasa-rockoon/WOBC/blob/aa941c142f3019fef4b720576778969fe941e1ff/src/library/process/process.h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 を使ってほしい）
module_idを変更したいときは`kernel::begin(module_id, false)`とすると，このチェックなしで上書きされる．

fujiy, 2024-09-02:
あと言い忘れてたけど，module_idをcomponent_idと被らないように決めてほしい

KeisukeSuganuma, 2024-09-02:
ありがとうございます。
一度モジュールIDを書き込んで置いて、それ以降はいじらないっていう認識で良いですかね？

id管理ですが一度話し合った気もするのですがそのファイルが行方不明でして、もし現時点で参照してたり決まっているものがあれば教えてもらえますか？無いようでしたら一から再度考えようと思います。

fujiy, 2024-09-02:
> 一度モジュールIDを書き込んで置いて、それ以降はいじらない

まあそうともいえるかな？別にユーザーが明示的に書き込む操作をするわけではない．`kernel::begin`は必ず呼ぶ

> id管理

https://docs.google.com/spreadsheets/d/1Nxq4RtOsuqMcLhA3_2kKKpubHb2iXEK-Q0oDwHh2aik/edit?usp=sharing
これかな
id管理と説明はこのリポジトリのdocs/modules.md とdocs/components.md に書いていこうか

KeisukeSuganuma, 2024-09-03:
手束とテレメの話して分かったんですけど、すでに考えてくれているidがあるそうなんですけど、これをベースにするのでも良いですかね。idとかって二文字である必要はないんでしたっけ？
tornado/lib/wcpp/id_name_mapping.json

fujiy, 2024-09-03:
任せる
unit, module, componentのidは8bitの数値．asciiコードで1文字にするのがわかりやすいかな
unit idは同じ種類でも被らないように

rogue1starwars, 2024-09-04:
私が考えたid はテレメトリのテストをするために仮で作ったものなので、自由に変えてもらってしまって大丈夫です。
私の方で勝手に必要そうなid を設定した形になります。

rogue1starwars, 2024-09-04:
このjsonファイルの主な用途としては、Grafanaに表示する情報のマッピングになります。Grafanaにデータを表示する際にエントリ名やパケット名などをそのまま表示していては分かりづらいため、分かりやすい名前にマッピングするためのjsonファイルを作成しました。

KeisukeSuganuma, 2024-09-04:
@rogue1starwars なるほど、ありがとう。
パケットの使い方どころかオブジェクト指向のコードの書き方に手こずってて勉強中だから手束の方でIDの管理というか設定をお願いできないかな。
componentとmoduleはmainのhardwareの中にあるファイルを参考にしてもらいたい。orderfileは発注したやつだから無視してくれて大丈夫

KeisukeSuganuma, 2024-09-04:
@rogue1starwars ごめんpacket idについて他に決めることだったりしたら新しくissue立てて

@fujiy すみませんコーディングについて相談で、CANとか使わないシンプルなTrackerからコードを書いていまして、今LiPoPoweコンポーネントからINA226のデータを取得する関数を書いています。初歩的な質問だと思うので本当に申し訳ないんですけど、icを使うときヘッダファイルを参照して（例えばINA226.hとか）その中の関数を使うと思うのですが、ヘッダファイルのどこで宣言すればよいのかわかんないです。

すごく抽象的になってしまったので具体的な問題を共有します。
ヘッダファイルがこちらで、LiPoPwerクラス内でina1とina2とina3を定義しています。

#include <library/wobc.h>
#include <Wire.h>
#include "INA226.h"

namespace component {

class LiPoPower: public process::Component {
public:
  static const uint8_t component_id = 0x22; // TBD
  static const uint8_t telemetry_id = 'P'; // TBD

  LiPoPower(TwoWire& wire, unsigned sample_freq_hz = 10/*TODO*/);

protected:
  TwoWire& wire_;
  INA226 ina1;
  INA226 ina2;
  INA226 ina3;

  void setup() override;

  class SampleTimer: public process::Timer {
  public:
    using process::Timer::Timer;

  protected:
    void callback() override;
  } sample_timer_;
};

}

そうすると定義する方のファイルでsetupとかはできるんですけど、SampleTimerクラス内でina1の関数が使えない状況です。どうやってエラーを解消すればよろしいでしょうか？

#include "lipo_power.h"

namespace component {

LiPoPower::LiPoPower(TwoWire& wire, unsigned sample_freq_hz /*TODO ピン設定*/)
  : process::Component("LiPoPower", component_id),
    wire_(wire),
    ina1(0x4F),
    ina2(0x4D),
    ina3(0x4E),
    sample_timer_("LiPoPowerTimer", 1000 / sample_freq_hz) {
}

void LiPoPower::setup() {
  start(sample_timer_);
  ina1.begin();
  ina2.begin();
  ina3.begin();
}

void LiPoPower::SampleTimer::callback() { // Timerで定期的に実行される関数

  int x1_mV = ina1.getBusVoltage() * 1000; // INA226センサー1のバス電圧（ミリボルト単位）
  int x1_mA = ina1.getCurrent_mA();        // INA226センサー1の電流（ミリアンペア単位）
  int x2_mV = ina2.getBusVoltage() * 1000; // INA226センサー2のバス電圧
  int x2_mA = ina2.getCurrent_mA();        // INA226センサー2の電流
  int x3_mV = ina3.getBusVoltage() * 1000; // INA226センサー3のバス電圧
  int x3_mA = ina3.getCurrent_mA();        // INA226センサー3の電流

  bool charging;

  wcpp::Packet packet = newPacket(64);
  packet.telemetry(telemetry_id, component_id());
  packet.append("V1").setInt(x1_mV); // センサー1の電圧
  packet.append("I1").setInt(x1_mA); // センサー1の電流
  packet.append("V2").setInt(x2_mV); // センサー2の電圧
  packet.append("I2").setInt(x2_mA); // センサー2の電流
  packet.append("V3").setInt(x3_mV); // センサー3の電圧
  packet.append("I3").setInt(x3_mA); // センサー3の電流
  packet.append("Ch").setBool(charging);
  // ... TODO

  sendPacket(packet);
}

}

fujiy, 2024-09-04:
SampleTimerがina1...の参照をメンバで持つようにして，コンストラクタで渡すのが一番素直かな

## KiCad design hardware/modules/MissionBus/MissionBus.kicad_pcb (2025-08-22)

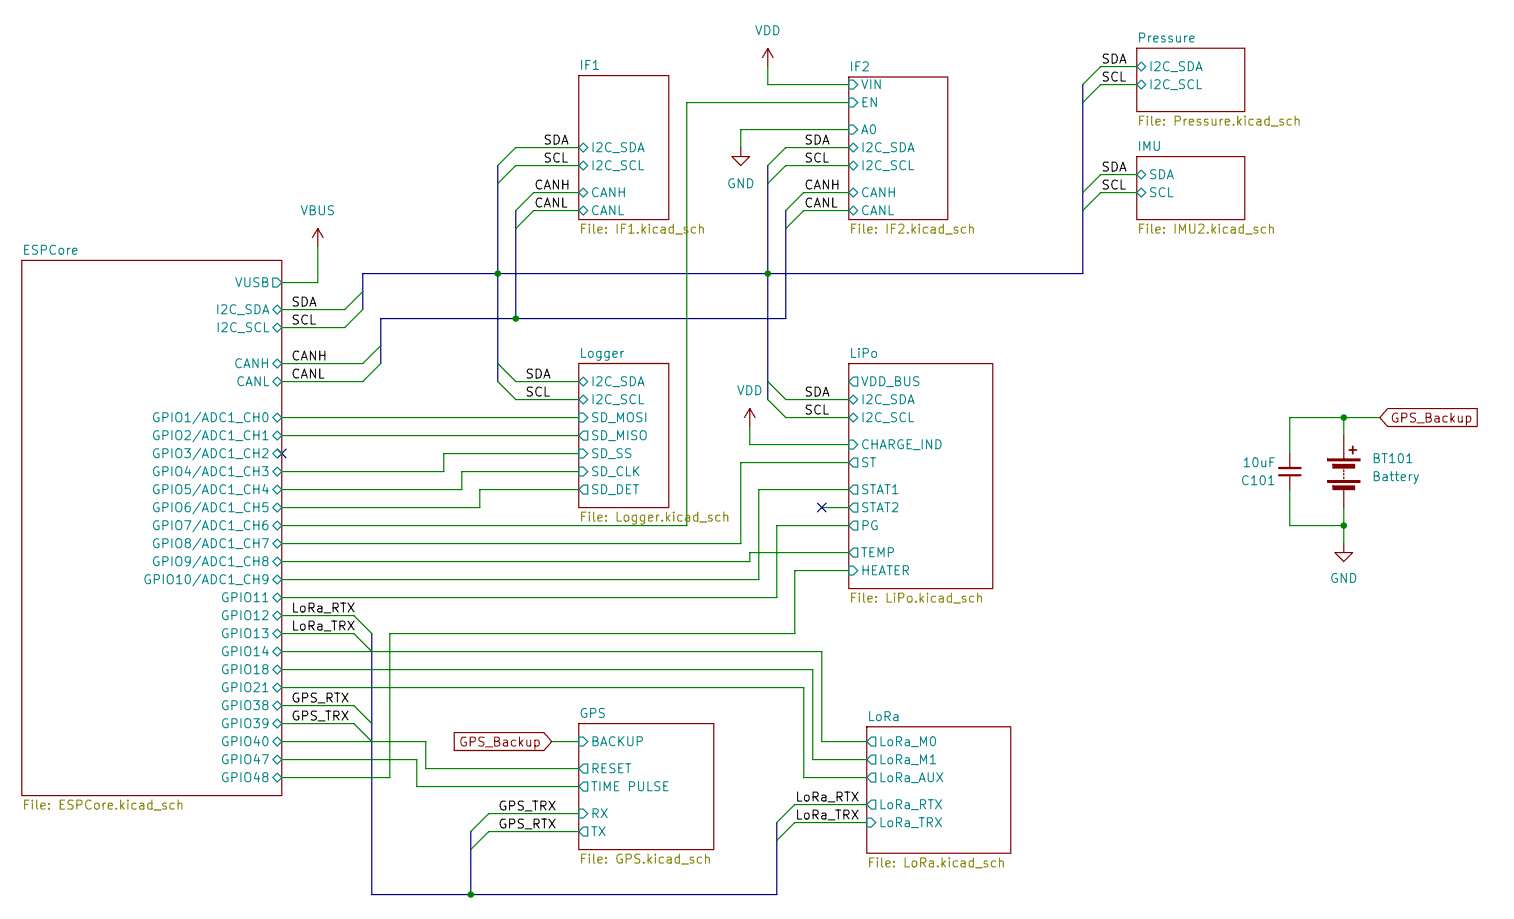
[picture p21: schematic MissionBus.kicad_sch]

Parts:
BT101: Battery; cr1220
C101: 10uF; C_0603_1608Metric; LCSC C19702

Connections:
GND: BT101.2 (-), C101.1; also elsewhere on the board
GPS_Backup: BT101.1 (+), C101.2; also elsewhere on the board

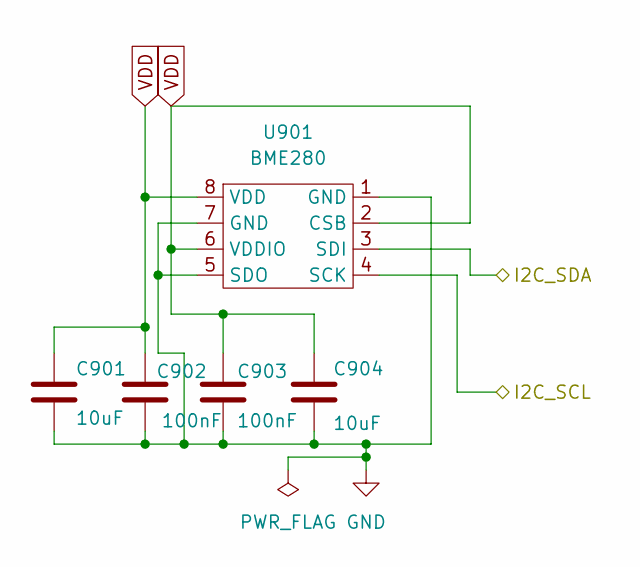
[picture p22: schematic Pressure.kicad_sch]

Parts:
C901, C904: 10uF; C_0603_1608Metric; LCSC C19702
C902, C903: 100nF; C_0402_1005Metric; LCSC C1525
U901: BME280; LCSC C92489

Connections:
/SCL: U901.4 (SCK); also elsewhere on the board
/SDA: U901.3 (SDI); also elsewhere on the board
GND: C901.2, C902.2, C903.2, C904.2, U901.1 (GND), U901.5 (SDO), U901.7 (GND); also elsewhere on the board
VDD: C901.1, C902.1, C903.1, C904.1, U901.2 (CSB), U901.6 (VDDIO), U901.8 (VDD); also elsewhere on the board

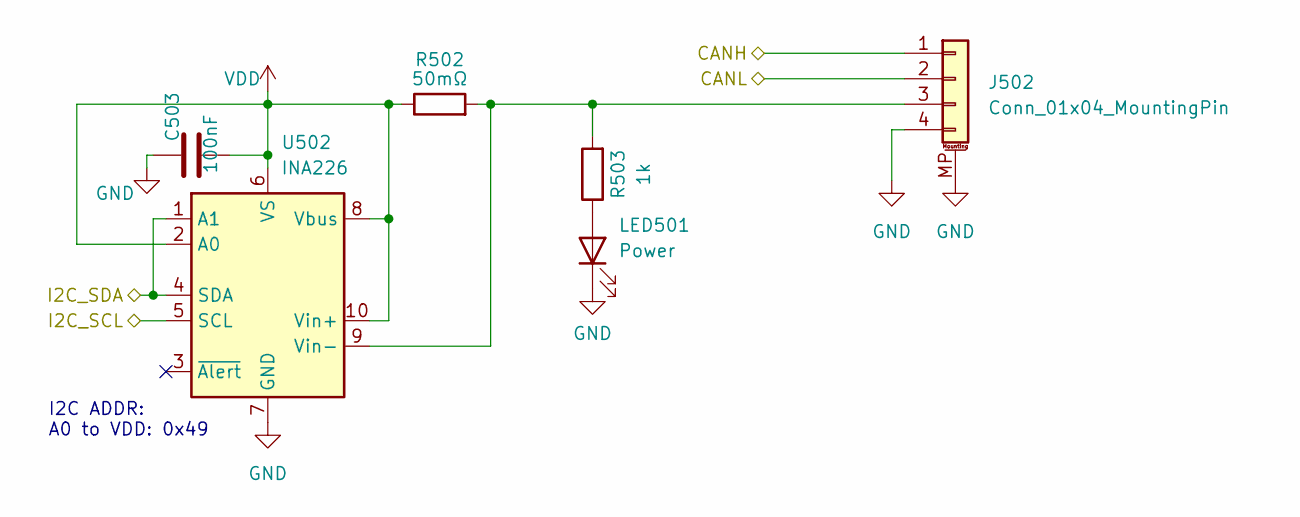
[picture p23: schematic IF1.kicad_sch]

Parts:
C503: 100nF; C_0402_1005Metric; LCSC C1525
J502: Conn_01x04_MountingPin; Grove_4P_L_SMD
LED501: Power; LED_0603_1608Metric; LCSC C2297
R502: 50mΩ; R_0805_2012Metric; LCSC C247602
R503: 1k; R_0402_1005Metric; LCSC C11702
U502: INA226; VSSOP-10_3x3mm_P0.5mm; LCSC C49851

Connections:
/CANH: J502.1; also elsewhere on the board
/CANL: J502.2; also elsewhere on the board
/SCL: U502.5 (SCL); also elsewhere on the board
/SDA: U502.1 (A1), U502.4 (SDA); also elsewhere on the board
GND: C503.1, J502.4, J502.MP (MountPin), LED501.1 (K), U502.7 (GND); also elsewhere on the board
unnamed: J502.3, R502.2, R503.2, U502.9 (Vin-)
unnamed: LED501.2 (A), R503.1
VDD: C503.2, R502.1, U502.2 (A0), U502.6 (VS), U502.8 (Vbus), U502.10 (Vin+); also elsewhere on the board

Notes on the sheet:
I2C ADDR: A0 to VDD: 0x49

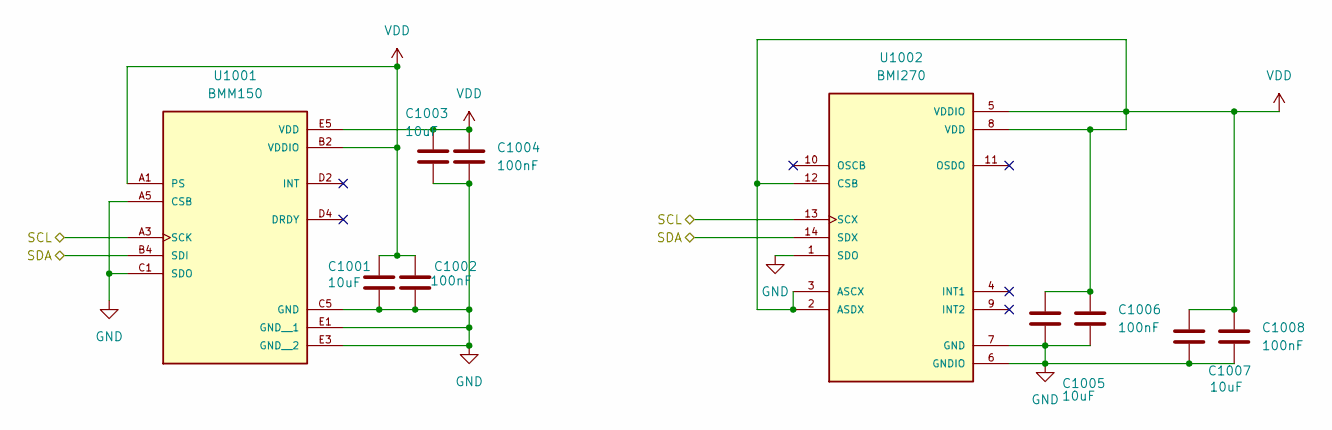
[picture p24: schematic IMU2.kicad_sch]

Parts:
C1001, C1003, C1005, C1007: 10uF; C_0603_1608Metric; LCSC C19702
C1002, C1004, C1006, C1008: 100nF; C_0402_1005Metric; LCSC C1525
U1001: BMM150; XDCR_BMM150
U1002: BMI270; XDCR_BMI270

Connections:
/SCL: U1001.A3 (SCK), U1002.13 (SCX); also elsewhere on the board
/SDA: U1001.B4 (SDI), U1002.14 (SDX); also elsewhere on the board
GND: C1001.2, C1002.2, C1003.2, C1004.2, C1005.2, C1006.2, C1007.2, C1008.2, U1001.A5 (CSB), U1001.C1 (SDO), U1001.C5 (GND), U1001.E1 (GND__1), U1001.E3 (GND__2), U1002.1 (SDO), U1002.6 (GNDIO), U1002.7 (GND); also elsewhere on the board
VDD: C1001.1, C1002.1, C1003.1, C1004.1, C1005.1, C1006.1, C1007.1, C1008.1, U1001.A1 (PS), U1001.B2 (VDDIO), U1001.E5 (VDD), U1002.2 (ASDX), U1002.3 (ASCX), U1002.5 (VDDIO), U1002.8 (VDD), U1002.12 (CSB); also elsewhere on the board

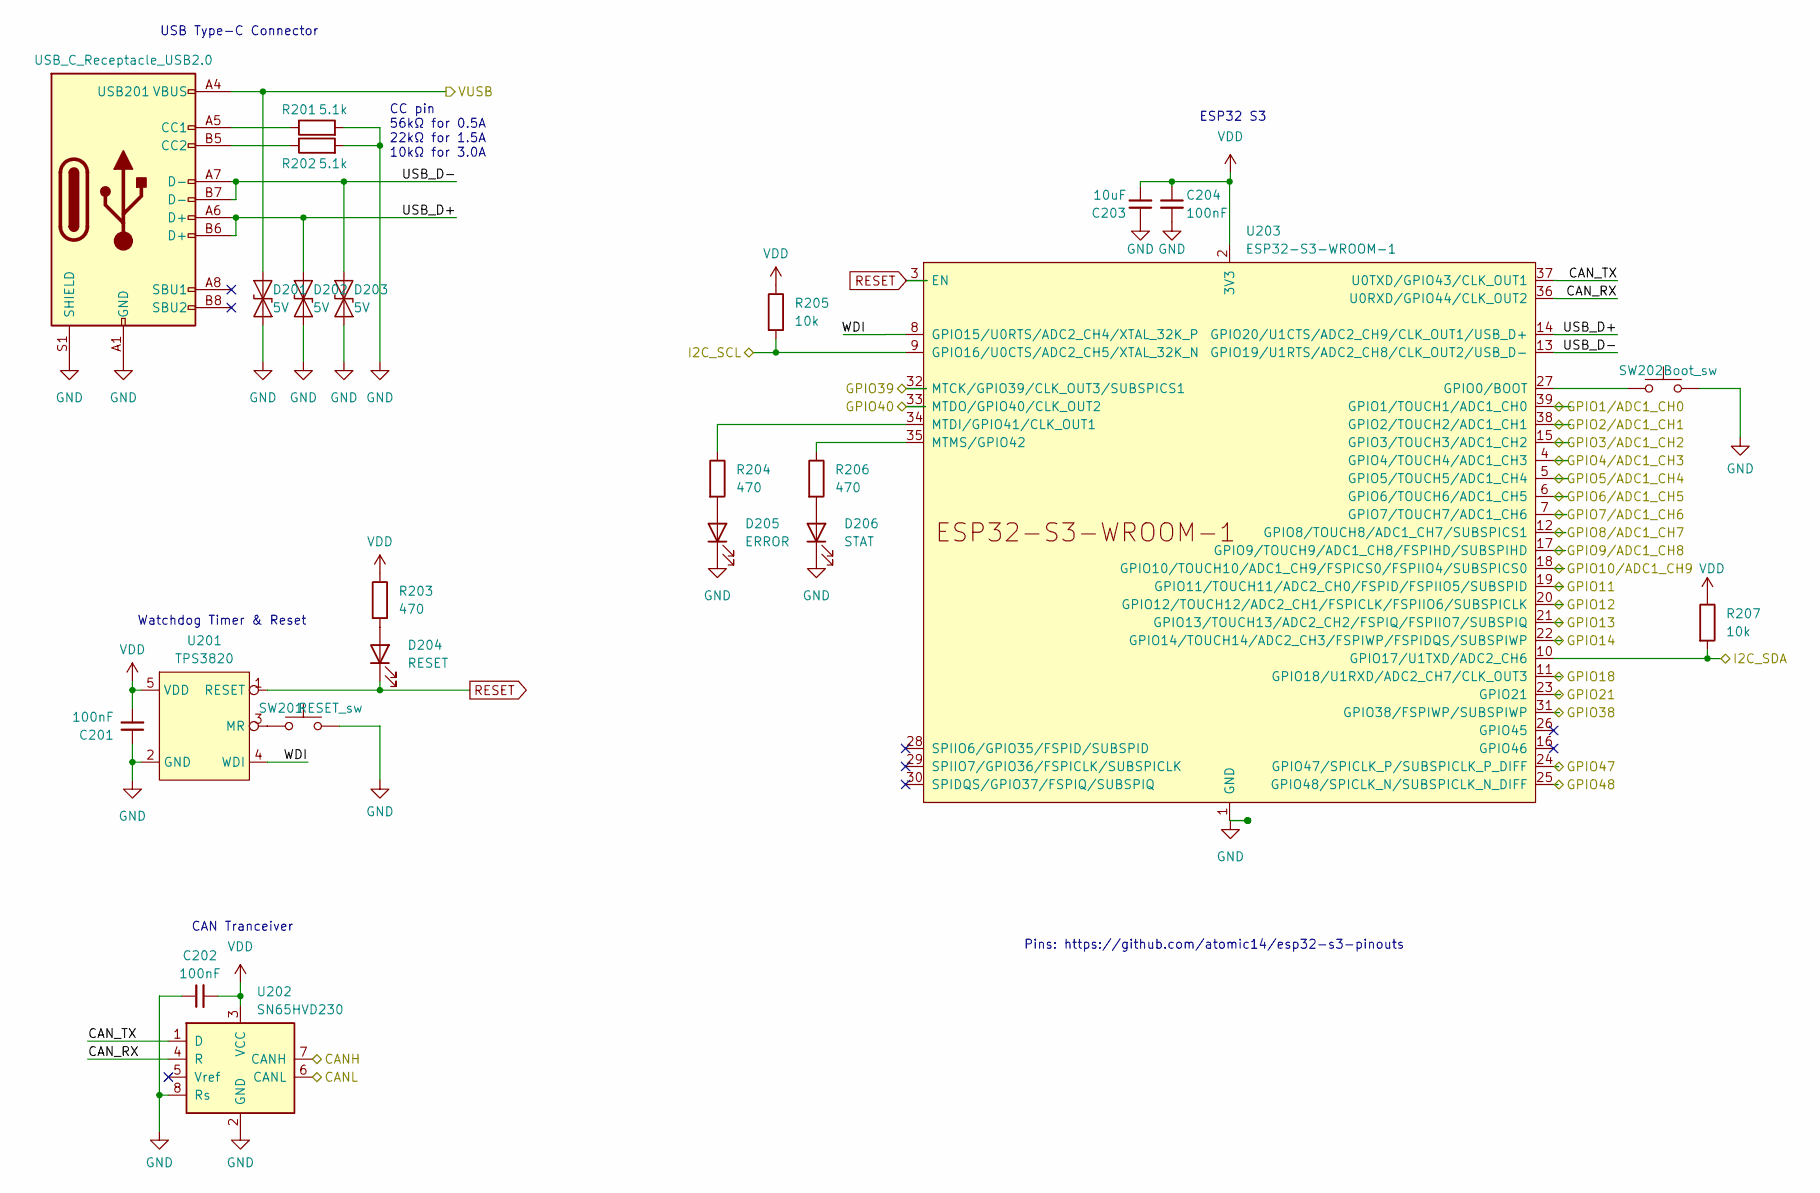
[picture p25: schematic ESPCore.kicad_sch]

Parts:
C201, C202, C204: 100nF; C_0402_1005Metric; LCSC C1525
C203: 10uF; C_0603_1608Metric; LCSC C19702
D201, D202, D203: 5V; D_SOD-882; LCSC C7420372
D204: RESET; LED_0805_2012Metric; LCSC C2296
D205: ERROR; LED_0805_2012Metric; LCSC C84256
D206: STAT; LED_0805_2012Metric; LCSC C2297
R201, R202: 5.1k; R_0402_1005Metric; LCSC C25905
R203, R204, R206: 470; R_0402_1005Metric; LCSC C25117
R205, R207: 10k; R_0402_1005Metric; LCSC C25744
SW201: RESET_sw; TVAF06-A020B-R
SW202: Boot_sw; TVAF06-A020B-R
U201: TPS3820; SOT-23-5; LCSC C7719
U202: SN65HVD230; SOIC-8_3.9x4.9mm_P1.27mm; LCSC C12084
U203: ESP32-S3-WROOM-1
USB201: USB_C_Receptacle_USB2.0; USB_C_TYPEC-301S-ACP16X7; LCSC C2856766

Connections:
/CANH: U202.7 (CANH); also elsewhere on the board
/CANL: U202.6 (CANL); also elsewhere on the board
/ESPCore/CAN_RX: U202.4 (R), U203.36 (U0RXD/GPIO44/CLK_OUT2)
/ESPCore/CAN_TX: U202.1 (D), U203.37 (U0TXD/GPIO43/CLK_OUT1)
/ESPCore/GPIO1/ADC1_CH0: U203.39 (GPIO1/TOUCH1/ADC1_CH0); also elsewhere on the board
/ESPCore/GPIO2/ADC1_CH1: U203.38 (GPIO2/TOUCH2/ADC1_CH1); also elsewhere on the board
/ESPCore/GPIO3/ADC1_CH2: U203.15 (GPIO3/TOUCH3/ADC1_CH2)
/ESPCore/GPIO4/ADC1_CH3: U203.4 (GPIO4/TOUCH4/ADC1_CH3); also elsewhere on the board
/ESPCore/GPIO5/ADC1_CH4: U203.5 (GPIO5/TOUCH5/ADC1_CH4); also elsewhere on the board
/ESPCore/GPIO6/ADC1_CH5: U203.6 (GPIO6/TOUCH6/ADC1_CH5); also elsewhere on the board
/ESPCore/GPIO7/ADC1_CH6: U203.7 (GPIO7/TOUCH7/ADC1_CH6); also elsewhere on the board
/ESPCore/GPIO8/ADC1_CH7: U203.12 (GPIO8/TOUCH8/ADC1_CH7/SUBSPICS1); also elsewhere on the board
/ESPCore/GPIO9/ADC1_CH8: U203.17 (GPIO9/TOUCH9/ADC1_CH8/FSPIHD/SUBSPIHD); also elsewhere on the board
/ESPCore/GPIO10/ADC1_CH9: U203.18 (GPIO10/TOUCH10/ADC1_CH9/FSPICS0/FSPIIO4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); also elsewhere on the board
/ESPCore/GPIO11: U203.19 (GPIO11/TOUCH11/ADC2_CH0/FSPID/FSPIIO5/S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); also elsewhere on the board
/ESPCore/GPIO14: U203.22 (GPIO14/TOUCH14/ADC2_CH3/FSPIWP/FSPIDQS/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); also elsewhere on the board
/ESPCore/GPIO18: U203.11 (GPIO18/U1RXD/ADC2_CH7/CLK_OUT3); also elsewhere on the board
/ESPCore/GPIO21: U203.23 (GPIO21); also elsewhere on the board
/ESPCore/GPIO40: U203.33 (MTDO/GPIO40/CLK_OUT2); also elsewhere on the board
/ESPCore/GPIO47: U203.24 (GPIO47/SPICLK_P/SUBSPICLK_P_DIFF); also elsewhere on the board
/ESPCore/GPIO48: U203.25 (GPIO48/SPICLK_N/SUBSPICLK_N_DIFF); also elsewhere on the board
/ESPCore/USB_D+: D202.2 (A2), U203.14 (GPIO20/U1CTS/ADC2_CH9/CLK_OUT1/USB_D+), USB201.A6 (D+), USB201.B6 (D+)
/ESPCore/USB_D-: D203.2 (A2), U203.13 (GPIO19/U1RTS/ADC2_CH8/CLK_OUT2/USB_D-), USB201.A7 (D-), USB201.B7 (D-)
/ESPCore/WDI: U201.4 (WDI), U203.8 (GPIO15/U0RTS/ADC2_CH4/XTAL_32K_P)
/GPS_RTX: U203.31 (GPIO38/FSPIWP/SUBSPIWP); also elsewhere on the board
/GPS_TRX: U203.32 (MTCK/GPIO39/CLK_OUT3/SUBSPICS1); also elsewhere on the board
/LoRa_RTX: U203.20 (GPIO12/TOUCH12/ADC2_CH1/FSPICLK/FSPIIO6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); also elsewhere on the board
/LoRa_TRX: U203.21 (GPIO13/TOUCH13/ADC2_CH2/FSPIQ/FSPIIO7/S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); also elsewhere on the board
/SCL: R205.2, U203.9 (GPIO16/U0CTS/ADC2_CH5/XTAL_32K_N); also elsewhere on the board
/SDA: R207.2, U203.10 (GPIO17/U1TXD/ADC2_CH6); also elsewhere on the board
GND: C201.1, C202.1, C203.1, C204.2, D201.1 (A1), D202.1 (A1), D203.1 (A1), D205.1 (K), D206.1 (K), R201.2, R202.2, SW201.2, SW202.2, U201.2 (GND), U202.2 (GND), U202.8 (Rs), U203.1 (GND), U203.40 (GND), U203.41 (GND), USB201.A1 (GND), USB201.A12 (GND), USB201.B1 (GND), USB201.B12 (GND), USB201.S1 (SHIELD); also elsewhere on the board
unnamed: D204.2 (A), R203.2
unnamed: D205.2 (A), R204.2
unnamed: D206.2 (A), R206.2
unnamed: SW201.1, U201.3 (MR)
unnamed: SW202.1, U203.27 (GPIO0/BOOT)
unnamed: R204.1, U203.34 (MTDI/GPIO41/CLK_OUT1)
unnamed: R206.1, U203.35 (MTMS/GPIO42)
unnamed: R201.1, USB201.A5 (CC1)
unnamed: R202.1, USB201.B5 (CC2)
RESET: D204.1 (K), U201.1 (RESET), U203.3 (EN)
VBUS: D201.2 (A2), USB201.A4 (VBUS), USB201.A9 (VBUS), USB201.B4 (VBUS), USB201.B9 (VBUS); also elsewhere on the board
VDD: C201.2, C202.2, C203.2, C204.1, R203.1, R205.1, R207.1, U201.5 (VDD), U202.3 (VCC), U203.2 (3V3); also elsewhere on the board

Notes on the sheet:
USB Type-C Connector
CC pin 56kΩ for 0.5A 22kΩ for 1.5A 10kΩ for 3.0A
Watchdog Timer & Reset
ESP32 S3
Pins: https://github.com/atomic14/esp32-s3-pinouts
CAN Tranceiver

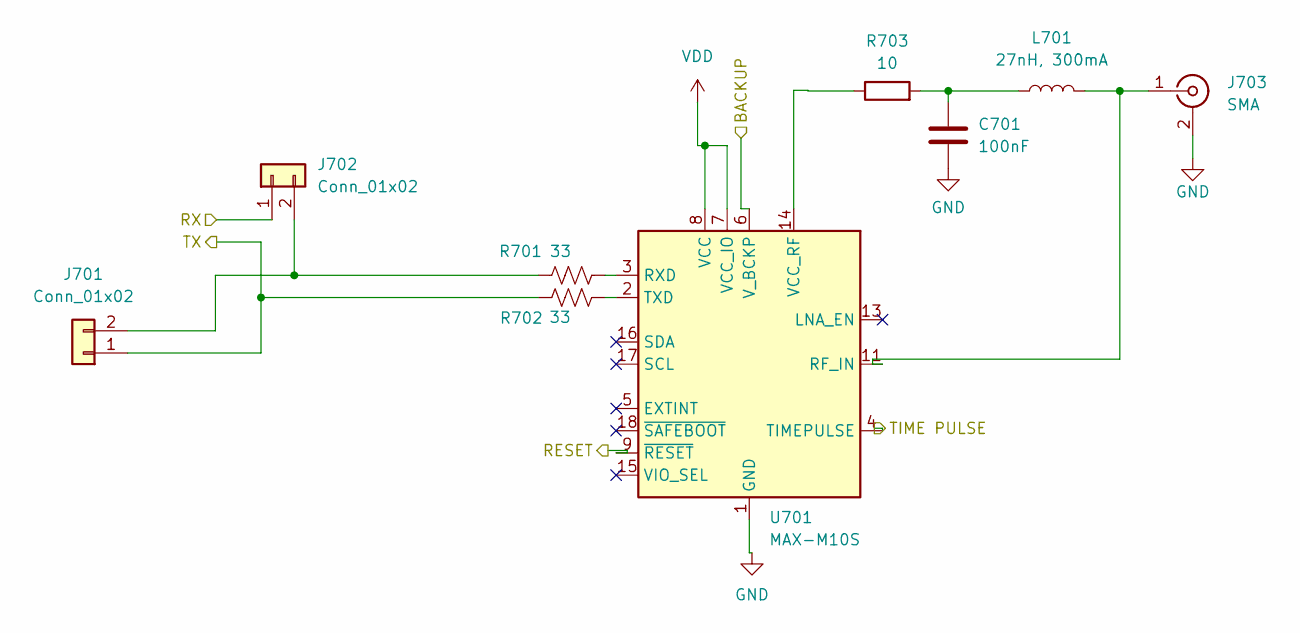
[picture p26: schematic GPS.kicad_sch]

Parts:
C701: 100nF; C_0402_1005Metric; LCSC C1525
J701, J702: Conn_01x02; PinHeader_1x02_P1.27mm_Vertical
J703: SMA; SMA_Amphenol_132203-12_Horizontal; LCSC C2693813
L701: 27nH, 300mA; L_0402_1005Metric; LCSC C18830
R701, R702: 33; R_0402_1005Metric; LCSC C25077
R703: 10; R_0402_1005Metric; LCSC C25077
U701: MAX-M10S; ublox_MAX

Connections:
/ESPCore/GPIO40: U701.9 (~RESET); also elsewhere on the board
/ESPCore/GPIO47: U701.4 (TIMEPULSE); also elsewhere on the board
/GPS_RTX: J701.1, R702.2; also elsewhere on the board
/GPS_TRX: J702.1; also elsewhere on the board
GND: C701.2, J703.2 (Ext), U701.1 (GND), U701.10 (GND), U701.12 (GND); also elsewhere on the board
GPS_Backup: U701.6 (V_BCKP); also elsewhere on the board
unnamed: C701.1, L701.1, R703.2
unnamed: J701.2, J702.2, R701.2
unnamed: J703.1 (In), L701.2, U701.11 (RF_IN)
unnamed: R701.1, U701.3 (RXD)
unnamed: R702.1, U701.2 (TXD)
unnamed: R703.1, U701.14 (VCC_RF)
VDD: U701.7 (VCC_IO), U701.8 (VCC); also elsewhere on the board

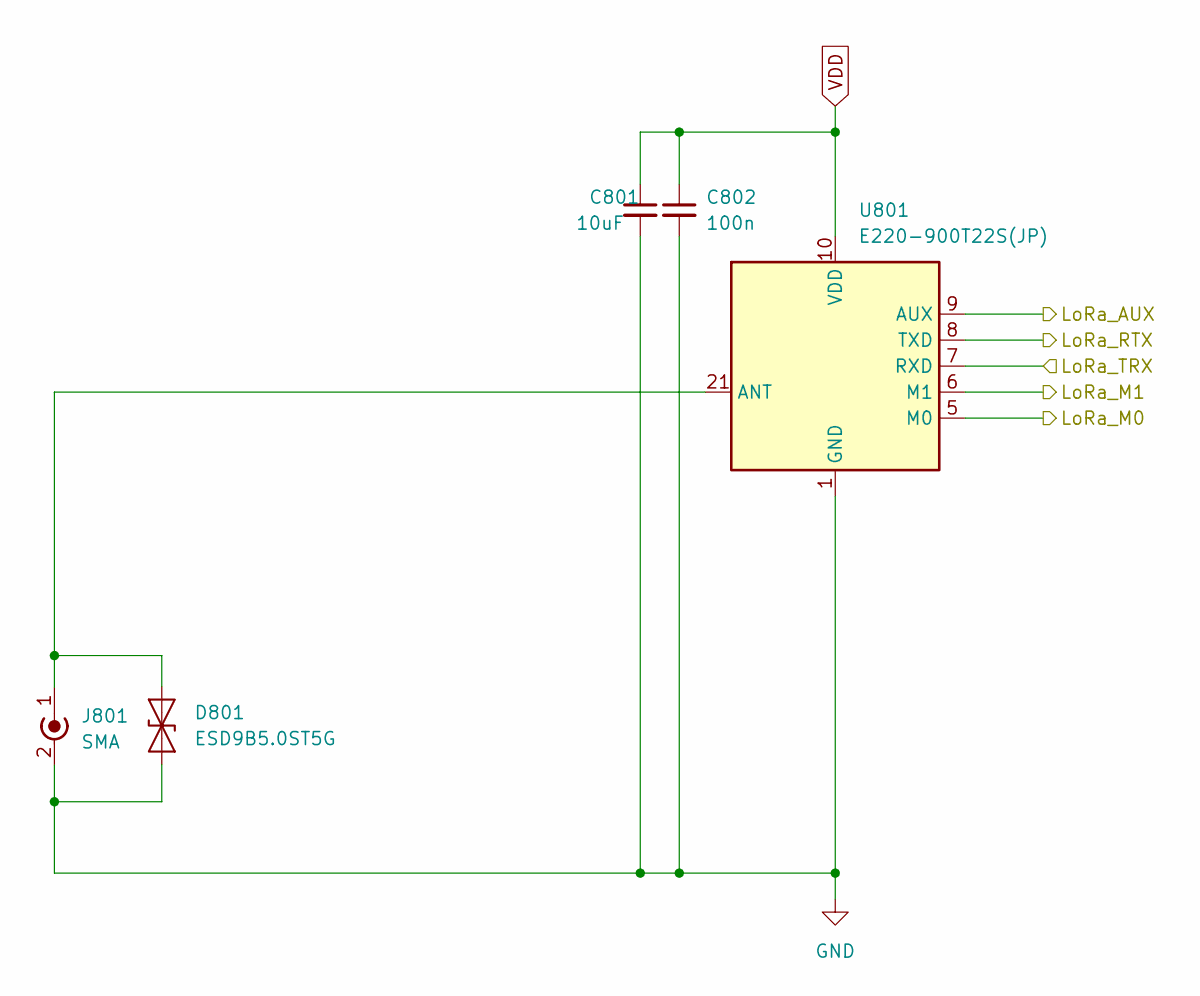
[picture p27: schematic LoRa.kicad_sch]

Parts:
C801: 10uF; C_0603_1608Metric; LCSC C19702
C802: 100n; C_0402_1005Metric; LCSC C1525
D801: ESD9B5.0ST5G; D_SOD-882; LCSC C7420372
J801: SMA; SMA_Amphenol_132203-12_Horizontal; LCSC C2693813
U801: E220-900T22S(JP)

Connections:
/ESPCore/GPIO14: U801.5 (M0); also elsewhere on the board
/ESPCore/GPIO18: U801.6 (M1); also elsewhere on the board
/ESPCore/GPIO21: U801.9 (AUX); also elsewhere on the board
/LoRa_RTX: U801.8 (TXD); also elsewhere on the board
/LoRa_TRX: U801.7 (RXD); also elsewhere on the board
GND: C801.2, C802.2, D801.1 (A1), J801.2 (Ext), U801.1 (GND), U801.2 (GND), U801.3 (GND), U801.4 (GND), U801.11 (GND), U801.13 (GND), U801.19 (GND), U801.20 (GND), U801.22 (GND); also elsewhere on the board
unnamed: D801.2 (A2), J801.1 (In), U801.21 (ANT)
VDD: C801.1, C802.1, U801.10 (VDD); also elsewhere on the board

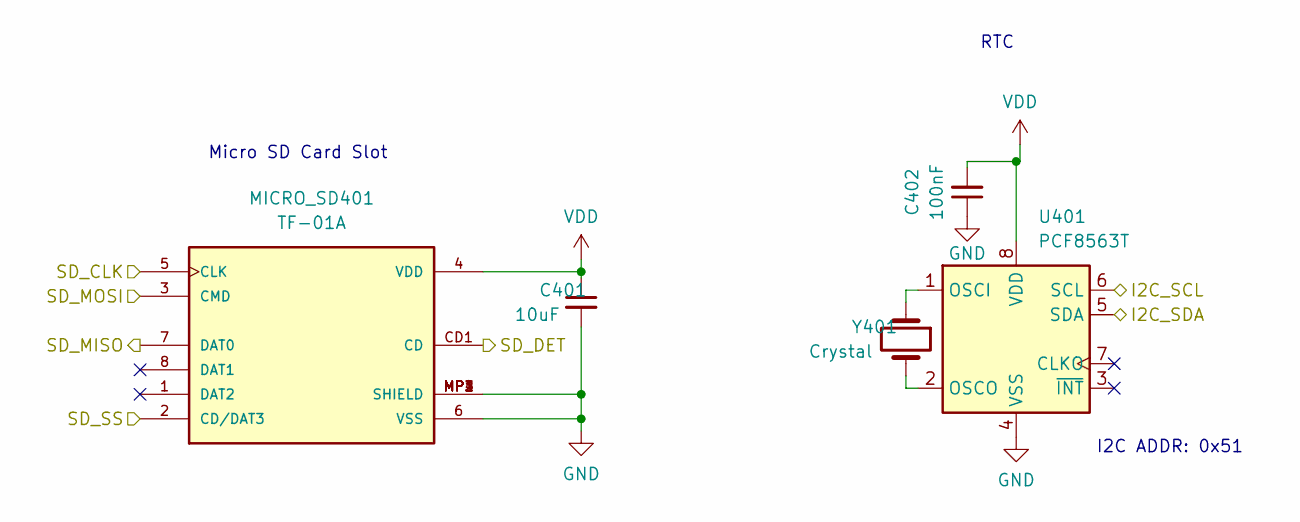
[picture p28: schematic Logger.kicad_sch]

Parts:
C401: 10uF; C_0603_1608Metric; LCSC C19702
C402: 100nF; C_0402_1005Metric; LCSC C1525
MICRO_SD401: TF-01A; LCSC C5155563
U401: PCF8563T; SOIC-8_3.9x4.9mm_P1.27mm; LCSC C7440
Y401: Crystal; Crystal_SMD_3215-2Pin_3.2x1.5mm; LCSC C32346

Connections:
/ESPCore/GPIO1/ADC1_CH0: MICRO_SD401.3 (CMD); also elsewhere on the board
/ESPCore/GPIO2/ADC1_CH1: MICRO_SD401.7 (DAT0); also elsewhere on the board
/ESPCore/GPIO4/ADC1_CH3: MICRO_SD401.2 (CD/DAT3); also elsewhere on the board
/ESPCore/GPIO5/ADC1_CH4: MICRO_SD401.5 (CLK); also elsewhere on the board
/ESPCore/GPIO6/ADC1_CH5: MICRO_SD401.CD1 (CD); also elsewhere on the board
/SCL: U401.6 (SCL); also elsewhere on the board
/SDA: U401.5 (SDA); also elsewhere on the board
GND: C401.2, C402.1, MICRO_SD401.6 (VSS), MICRO_SD401.MP1 (SHIELD), MICRO_SD401.MP2 (SHIELD), MICRO_SD401.MP3 (SHIELD), MICRO_SD401.MP4 (SHIELD), U401.4 (VSS); also elsewhere on the board
unnamed: U401.1 (OSCI), Y401.1
unnamed: U401.2 (OSCO), Y401.2
VDD: C401.1, C402.2, MICRO_SD401.4 (VDD), U401.8 (VDD); also elsewhere on the board

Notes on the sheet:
I2C ADDR: 0x51
RTC
Micro SD Card Slot

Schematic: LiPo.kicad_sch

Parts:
C301, C302, C303, C305, C306, C310, C312: 10uF; C_0603_1608Metric; LCSC C19702
C304, C309, C311, C316: 100nF; C_0402_1005Metric; LCSC C1525
C307, C308, C313, C314, C315: 22uF; C_0805_2012Metric; LCSC C45783
F301, F302, F303: Polyfuse; Fuse_1206_3216Metric; LCSC C883133
J301: Battery; JST_XH_S2B-XH-A_1x02_P2.50mm_Horizontal
J302: Temp&Heater; JST_PH_S3B-PH-K_1x03_P2.00mm_Horizontal
J303: Ext Switch; JST_PH_S2B-PH-K_1x02_P2.00mm_Horizontal
J304: Conn_01x02; PinHeader_1x02_P1.27mm_Vertical
J305: LiPo; JST_PH_S2B-PH-K_1x02_P2.00mm_Horizontal
L301: L; L_Wuerth_WE-TPC-3816; LCSC C3033018
LED301: USB Power; LED_0805_2012Metric; LCSC C2297
LED302: CHARGE; LED_0805_2012Metric; LCSC C2296
LED303: Backup; LED_0805_2012Metric; LCSC C2296
LED304: Heater; LED_0805_2012Metric; LCSC C2296
LED305: VDD; LED_0805_2012Metric; LCSC C2297
Q301: Q_NPN_BEC; SOT-23; LCSC C20526
Q302: Q_PMOS_GSD; SOT-23; LCSC C15127
R301, R302, R303, R309, R312, R322: 1k; R_0402_1005Metric; LCSC C11702
R304, R305, R307, R310, R318: 100k; R_0402_1005Metric; LCSC C25741
R306, R320: 47k; R_0402_1005Metric; LCSC C25792
R308, R311, R314, R315: 10k; R_0402_1005Metric; LCSC C25744
R313, R317, R321: 50mΩ; R_0805_2012Metric; LCSC C247602
R316: 330k; R_0402_1005Metric; LCSC C25778
R319: 15k; R_0402_1005Metric; LCSC C25756
RV301: 10k; Potentiometer_Bourns_TC33X_Vertical; LCSC C719176
U301: MCP73871-1CC; QFN-20-1EP_4x4mm_P0.5mm_EP2.5x2.5mm; LCSC C511310
U302: TPS2116DRL; SOT-583-8
U303, U304, U306: INA226; VSSOP-10_3x3mm_P0.5mm; LCSC C49851
U305: TPS63070RNMR; VREG_TPS63070RNMR; LCSC C109322

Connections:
/ESPCore/GPIO8/ADC1_CH7: R309.2, U302.8 (ST); also elsewhere on the board
/ESPCore/GPIO9/ADC1_CH8: J302.2, J304.1, U301.5 (THERM); also elsewhere on the board
/ESPCore/GPIO10/ADC1_CH9: LED302.1 (K), U301.8 (STAT1/~LBO); also elsewhere on the board
/ESPCore/GPIO11: U301.6 (~PG); also elsewhere on the board
/ESPCore/GPIO48: R308.2; also elsewhere on the board
/LiPo/PROG: RV301.2, U301.13 (PROG1)
/LiPo/STAT2: U301.7 (STAT2)
/LiPo/VDD_BUS: C312.1, C313.1, C314.1, C315.1, C316.1, R318.1, R320.2, R321.1, U305.7_8 (VOUT), U306.6 (VS), U306.8 (Vbus), U306.10 (Vin+)
/SCL: U303.1 (A1), U303.5 (SCL), U304.1 (A1), U304.2 (A0), U304.5 (SCL), U306.1 (A1), U306.5 (SCL); also elsewhere on the board
/SDA: U303.4 (SDA), U304.4 (SDA), U306.2 (A0), U306.4 (SDA); also elsewhere on the board
GND: C301.2, C302.2, C303.2, C304.2, C305.2, C306.2, C307.2, C308.2, C309.2, C310.2, C311.2, C312.2, C313.2, C314.2, C315.2, C316.2, J301.2, J302.3, J305.2, Q301.2 (E), R301.2, R303.2, R304.2, R306.1, R310.2, R312.1, R315.2, R316.2, R319.1, R322.2, U301.9 (~TE), U301.10 (V_{SS}), U301.11 (V_{SS}), U301.21 (V_{SS}), U302.1 (GND), U303.7 (GND), U304.7 (GND), U305.4 (GND), U305.10 (PGND), U305.15 (VSEL), U306.7 (GND); also elsewhere on the board
unnamed: F302.1, J301.1
unnamed: J302.1, LED304.2 (A), Q302.3 (D)
unnamed: J303.1, R314.1
unnamed: J303.2, R316.1, U303.3 (~Alert), U305.1 (PS/SYNC), U305.14 (EN), U306.3 (~Alert)
unnamed: J304.2, R315.1
unnamed: F303.2, J305.1
unnamed: C301.1, F301.2, LED301.2 (A), R305.1, U301.2 (VPCC), U301.3 (SEL), U301.18 (IN), U301.19 (IN)
unnamed: LED301.1 (K), R301.1
unnamed: LED302.2 (A), R302.1
unnamed: LED303.1 (K), R309.1
unnamed: LED304.1 (K), R312.2
unnamed: LED305.1 (K), R322.1
unnamed: Q301.1 (B), R308.1, R310.1
unnamed: Q301.3 (C), Q302.1 (G), R311.2
unnamed: R303.1, RV301.3
unnamed: R305.2, U301.17 (CE), U304.3 (~Alert)
unnamed: R304.1, U301.12 (PROG3)
unnamed: C306.1, R317.1, U301.14 (V_{BAT}), U301.15 (V_{BAT}), U301.16 (V_{BAT_SENSE}), U304.9 (Vin-)
unnamed: C303.1, C305.1, R307.1, U301.1 (OUT), U301.20 (OUT), U302.3 (VIN1), U302.5 (MODE)
unnamed: R306.2, R307.2, U302.4 (PR1)
unnamed: C302.1, F302.2, U302.6 (VIN2)
unnamed: C307.1, C308.1, C310.1, R313.2, R314.2, U303.9 (Vin-), U305.12_13 (VIN)
unnamed: F303.1, R317.2, U304.8 (Vbus), U304.10 (Vin+)
unnamed: R319.2, R320.1, U305.5 (FB)
unnamed: L301.1, U305.11 (L1)
unnamed: L301.2, U305.9 (L2)
unnamed: R318.2, U305.2 (PG)
unnamed: C311.1, U305.3 (VAUX)
VBUS: F301.1; also elsewhere on the board
VDD: LED305.2 (A), R302.2, R321.2, U306.9 (Vin-); also elsewhere on the board
VPP: C304.1, C309.1, LED303.2 (A), Q302.2 (S), R311.1, R313.1, U302.2 (VOUT), U302.7 (VOUT), U303.2 (A0), U303.6 (VS), U303.8 (Vbus), U303.10 (Vin+), U304.6 (VS)

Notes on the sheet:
6V Max
I2C ADDR: 0x4D
-> 3.3V Output
Backup Battery ->
USB Bus Power ->
I2C ADDR: 0x4E
<-> LiPo
I2C ADDR: 0x4F

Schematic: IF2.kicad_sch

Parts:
C601, C602, C603: 100nF; C_0402_1005Metric; LCSC C1525
J602: Conn_01x04_MountingPin; Grove_4P_L_SMD
LED601: Power; LED_0603_1608Metric; LCSC C2297
R601: 10k; R_0402_1005Metric; LCSC C25744
R602: 50mΩ; R_0805_2012Metric; LCSC C247602
R603: 1k; R_0402_1005Metric; LCSC C11702
U601: TCK106AF; WCSPD-4(0.8x0.8); LCSC C146305
U602: INA226; VSSOP-10_3x3mm_P0.5mm; LCSC C49851

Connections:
/CANH: J602.1; also elsewhere on the board
/CANL: J602.2; also elsewhere on the board
/ESPCore/GPIO7/ADC1_CH6: R601.1; also elsewhere on the board
/SCL: U602.5 (SCL); also elsewhere on the board
/SDA: U602.1 (A1), U602.4 (SDA); also elsewhere on the board
GND: C601.1, C602.1, C603.1, J602.4, J602.MP (MountPin), LED601.1 (K), U601.2 (GND), U602.2 (A0), U602.7 (GND); also elsewhere on the board
unnamed: J602.3, R602.2, R603.2, U602.9 (Vin-)
unnamed: LED601.2 (A), R603.1
unnamed: R601.2, U601.3 (CONTROL), U602.3 (~Alert)
unnamed: C602.2, R602.1, U601.1 (VOUT), U602.8 (Vbus), U602.10 (Vin+)
VDD: C601.2, C603.2, U601.5 (VIN), U602.6 (VS); also elsewhere on the board

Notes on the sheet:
I2C ADDR: A0 to GND: 0x48

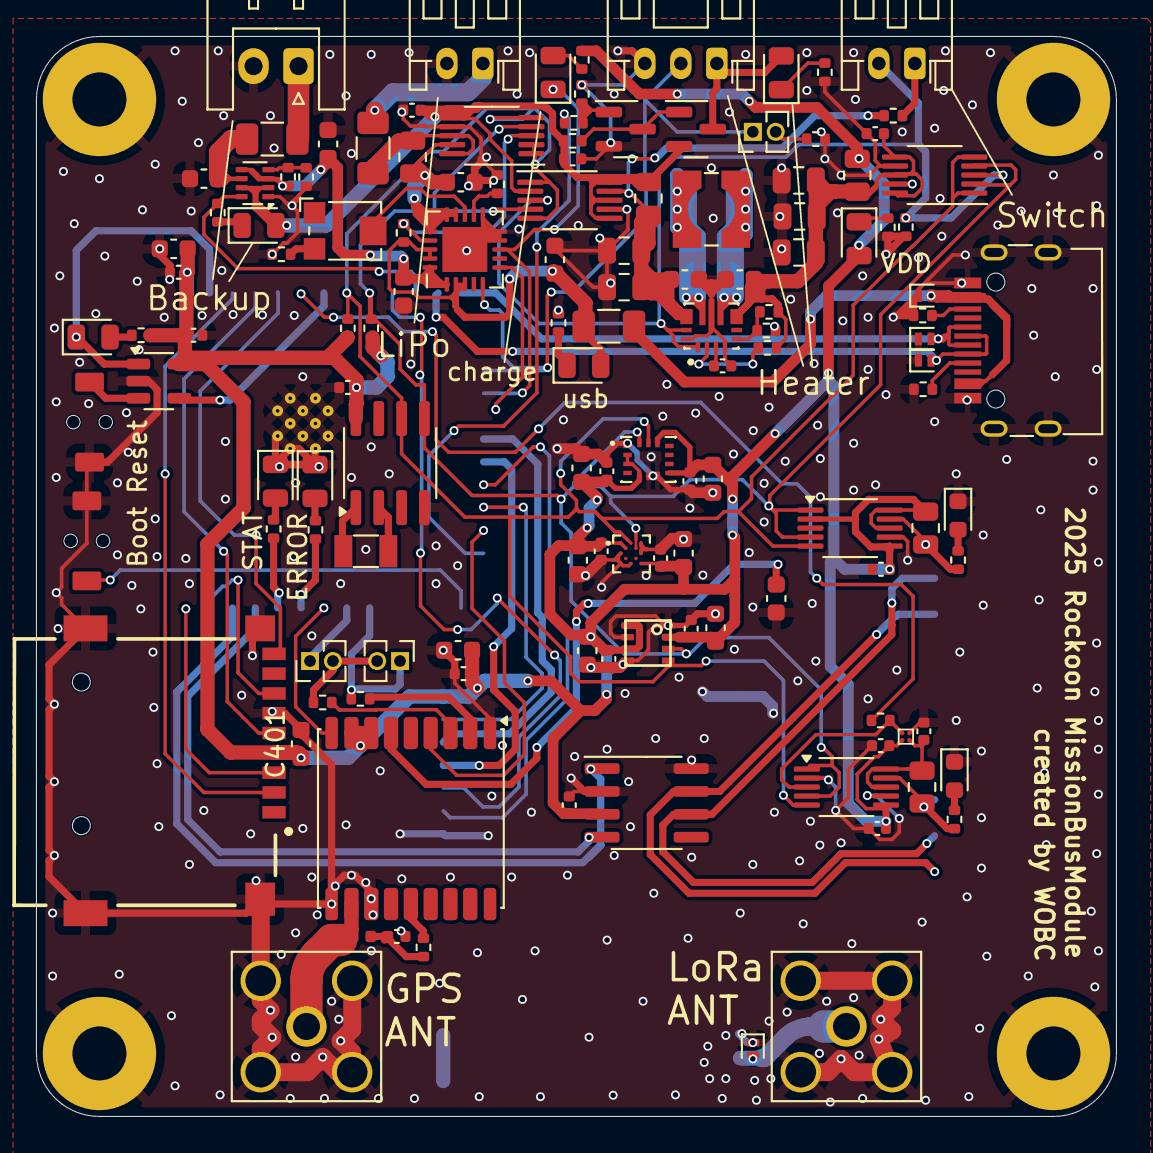
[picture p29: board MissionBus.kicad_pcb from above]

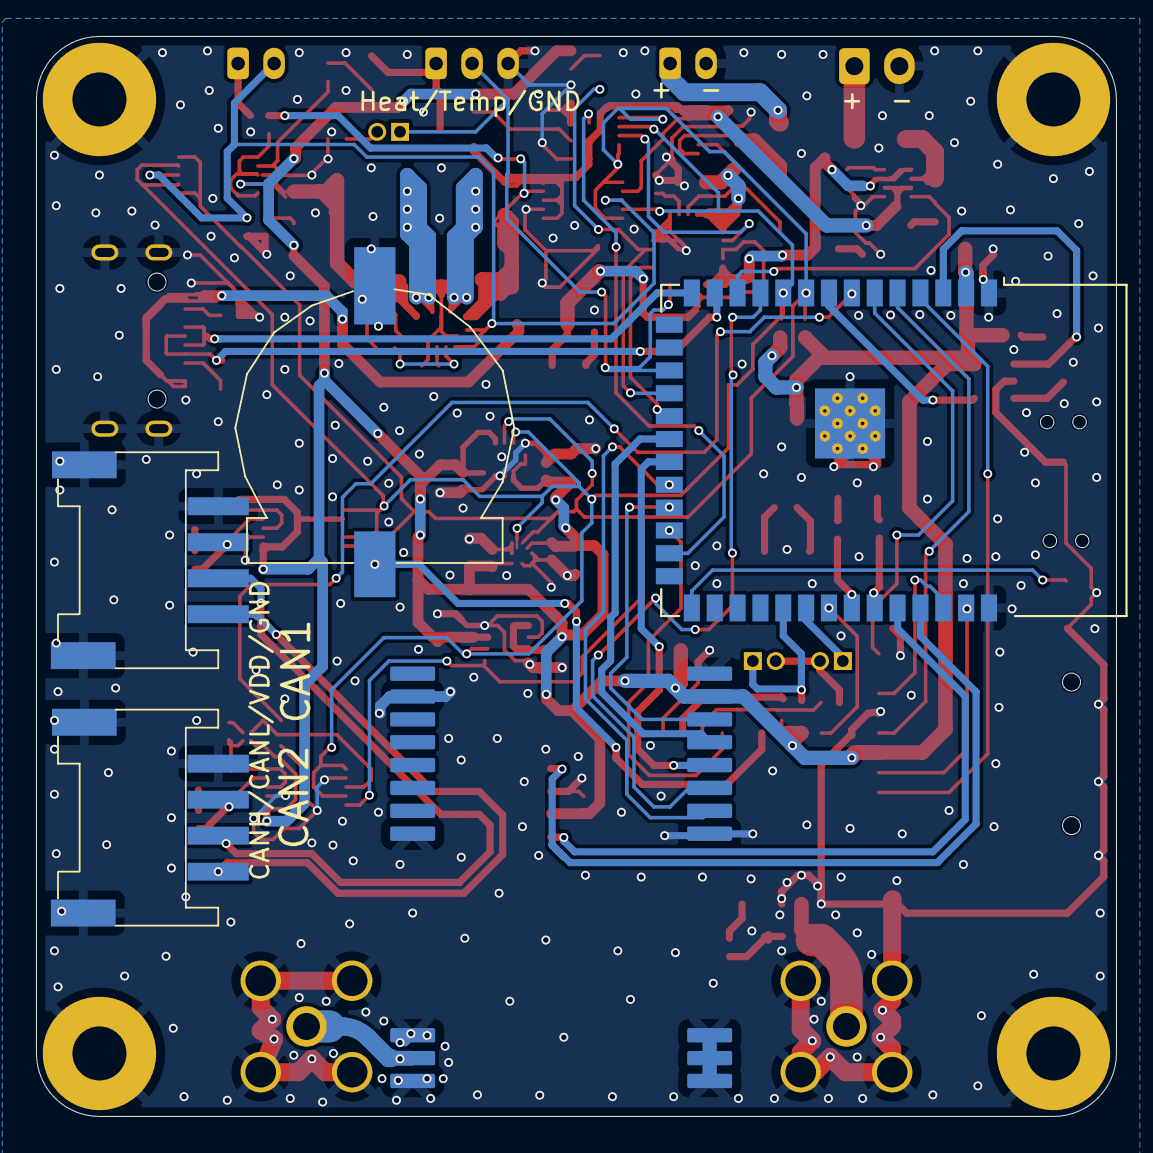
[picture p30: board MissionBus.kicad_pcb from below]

Board: 2 copper layers, 60.0 x 60.0 mm, 136 parts (5 on the bottom side), 89 nets.

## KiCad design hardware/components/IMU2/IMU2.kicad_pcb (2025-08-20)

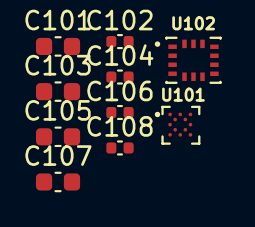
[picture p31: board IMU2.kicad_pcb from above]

Board: 2 copper layers, 10 parts (0 on the bottom side), 4 nets, no tracks yet.

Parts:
C101, C103, C105, C107: 10uF; C_0603_1608Metric
C102, C104, C106, C108: 100nF; C_0402_1005Metric
U101: BMM150; XDCR_BMM150
U102: BMI270; XDCR_BMI270

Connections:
/SCL: U101.A3 (SCK), U102.13 (SCX)
/SDA: U101.B4 (SDI), U102.14 (SDX)
GND: C101.2, C102.2, C103.2, C104.2, C105.2, C106.2, C107.2, C108.2, U101.A5 (CSB), U101.C1 (SDO), U101.C5 (GND), U101.E1 (GND__1), U101.E3 (GND__2), U102.1 (SDO), U102.6 (GNDIO), U102.7 (GND)
VDD: C101.1, C102.1, C103.1, C104.1, C105.1, C106.1, C107.1, C108.1, U101.A1 (PS), U101.B2 (VDDIO), U101.E5 (VDD), U102.2 (ASDX), U102.3 (ASCX), U102.5 (VDDIO), U102.8 (VDD), U102.12 (CSB)

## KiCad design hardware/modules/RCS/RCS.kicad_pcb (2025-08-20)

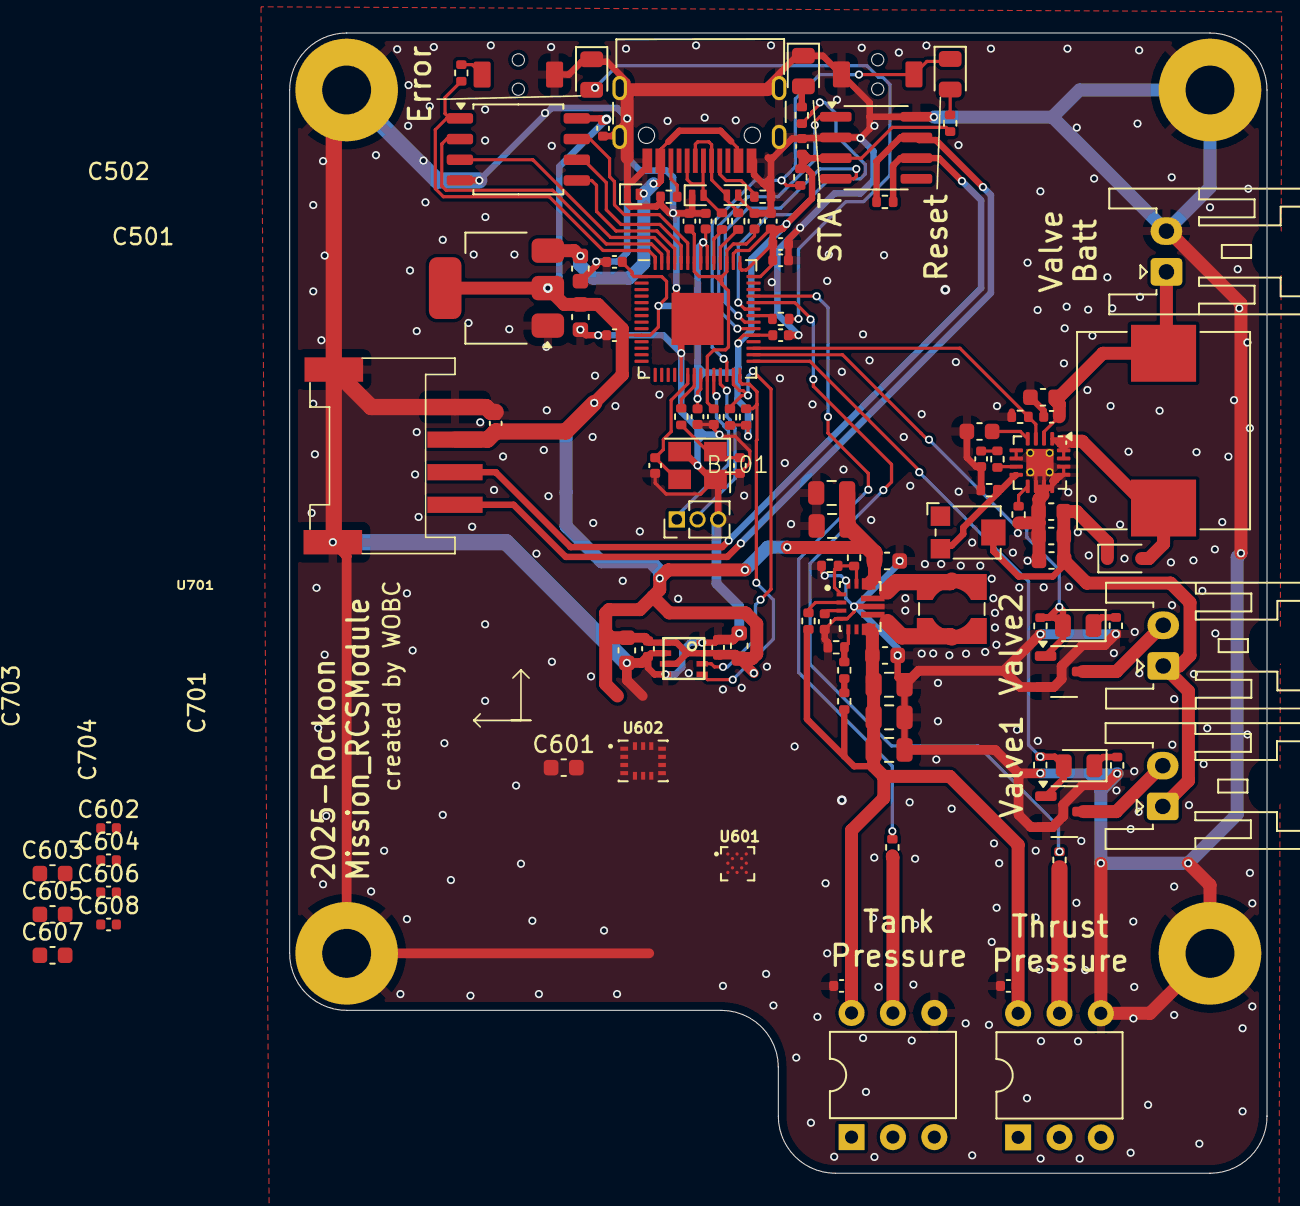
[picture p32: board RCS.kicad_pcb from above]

Board: 2 copper layers, 60.0 x 70.0 mm, 111 parts (0 on the bottom side), 61 nets.

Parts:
B101: Board_1U_60x70
C101, C102: 10u; C_0603_1608Metric
C201, C202, C205, C206, C208, C210, C211, C212, C213, C214, C215, C301, C504, C509, C510, C602, C604, C606, C608, C702, C703: 100nF; C_0402_1005Metric
C203, C204: 27pF; C_0402_1005Metric
C207, C209: 1uF; C_0402_1005Metric
C401: 47nF; C_0603_1608Metric
C402, C503, C505, C601, C603, C605, C607: 10uF; C_0603_1608Metric
C403, C404: 0.1uF; C_0402_1005Metric
C405, C406, C407: 4.7uF; C_0603_1608Metric
C501, C502, C506, C507, C508: 22uF; C_0805_2012Metric
C701, C704: 10μF; C_0603_1608Metric
D201: RESET; LED_0805_2012Metric
D202, D203, D204: 5V; D_SOD-882
D205: STAT; LED_0805_2012Metric
D206: ERROR; LED_0805_2012Metric
D401: D; D_SOD-323
D402, D403: LED; D_0805_2012Metric
J101, J401, J402: Conn_01x02; JST_XA_S02B-XASK-1_1x02_P2.50mm_Horizontal
J201: DEBUG; PinHeader_1x03_P1.27mm_Vertical
J301: Conn_01x04_MountingPin; Grove_4P_L_SMD
L401: L; L_Chilisin_BMRF00101040
L501: L; L_Wuerth_WE-TPC-3816
Q401, Q402: Q_NMOS_GSD; SOT-23-3
R201, R209, R211, R501, R504: 10k; R_0402_1005Metric
R202, R205, R208, R210, R212, R404, R405, R407, R505, R507, R508: 1k; R_0402_1005Metric
R203, R204: 5.1k; R_0402_1005Metric
R206, R207: 22.4; R_0402_1005Metric
R301: 120; R_0402_1005Metric
R401, R402, R406, R408, R503: 100k; R_0402_1005Metric
R403: 2.2k; R_0402_1005Metric
R502: 330k; R_0402_1005Metric
R506: 51k; R_0402_1005Metric
RV401: 20k; Potentiometer_Bourns_TC33X_Vertical
SW201: RESET_sw; TVAF06-A020B-R
SW202: BOOT0; TVAF06-A020B-R
U101: AMS1117-3.3; SOT-223-3_TabPin2
U201: SN65HVD230; SOIC-8_3.9x4.9mm_P1.27mm
U202: W25Q128JVS; SOIC-8_5.3x5.3mm_P1.27mm
U203: RP2040; QFN-56-1EP_7x7mm_P0.4mm_EP3.2x3.2mm
U401: WQFN-16-1EP_3x3mm_P0.5mm_EP1.68x1.68mm_ThermalVias
U501: TPS63070RNMR; VREG_TPS63070RNMR
U502, U503: DIP-6_W7.62mm
U601: BMM150; XDCR_BMM150
U602: BMI270; XDCR_BMI270
U701: BME280
USB201: USB_C_Receptacle_USB2.0; USB_C_TYPEC-301S-ACP16X7
Y201: Crystal_GND24; Crystal_SMD_3225-4Pin_3.2x2.5mm

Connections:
/IF/CANH: J301.1, R301.2, U201.7 (CANH)
/IF/CANL: J301.2, R301.1, U201.6 (CANL)
/RCS/RCS_EN: R401.1, U203.31 (GPIO20), U401.3 (EN)
/RCS/valve1: D402.2 (A), Q401.1 (G), R406.1, U203.30 (GPIO19)
/RCS/valve2: D403.2 (A), Q402.1 (G), R408.1, U203.29 (GPIO18)
/RP2040/CAN_RX: U201.4 (R), U203.35 (GPIO23)
/RP2040/CAN_TX: U201.1 (D), U203.34 (GPIO22)
/RP2040/GPIO26_ADC0: R507.2, U203.38 (GPIO26_ADC0)
/RP2040/GPIO27_ADC1: R508.2, U203.39 (GPIO27_ADC1)
/RP2040/USB_D+: D203.2 (A2), R206.1, USB201.A6 (D+), USB201.B6 (D+)
/RP2040/USB_D-: D204.2 (A2), R207.1, USB201.A7 (D-), USB201.B7 (D-)
/SCL: R211.2, U203.28 (GPIO17), U601.A3 (SCK), U602.13 (SCX), U701.4 (SCK)
/SDA: R209.2, U203.27 (GPIO16), U601.B4 (SDI), U602.14 (SDX), U701.3 (SDI)
GND: B101.GND, C101.2, C102.2, C201.1, C202.1, C203.1, C204.1, C205.2, C206.2, C207.1, C208.2, C209.1, C210.2, C211.2, C212.2, C213.2, C214.2, C215.2, C301.1, C401.2, C402.2, C403.2, C404.2, C405.2, C406.2, C407.2, C501.2, C502.2, C503.2, C504.2, C505.2, C506.2, C507.2, C508.2, C509.2, C510.2, C601.2, C602.2, C603.2, C604.2, C605.2, C606.2, C607.2, C608.2, C701.2, C702.2, C703.2, C704.2, D202.1 (A1), D203.1 (A1), D204.1 (A1), D205.1 (K), D206.1 (K), J101.2, J201.3, J301.4, J301.MP (MountPin), Q401.2 (S), Q402.2 (S), R203.2, R204.2, R401.2, R402.2, R404.2, R405.2, R406.2, R407.2, R408.2, R502.2, R504.1, SW201.2, SW202.1, U101.1 (GND), U201.2 (GND), U201.8 (Rs), U202.4 (GND), U203.19 (TESTEN), U203.57 (GND), U401.5 (SYNC), U401.6 (AGND), U401.10 (NC), U401.11 (PGND), U401.12 (PGND), U401.13 (PGND), U401.14 (NC), U401.17 (EP), U501.4 (GND), U501.10 (PGND), U501.15 (VSEL), U502.6 (GND), U503.6 (GND), U601.A5 (CSB), U601.C1 (SDO), U601.C5 (GND), U601.E1 (GND__1), U601.E3 (GND__2), U602.1 (SDO), U602.6 (GNDIO), U602.7 (GND), U701.1 (GND), U701.5 (SDO), U701.7 (GND), USB201.A1 (GND), USB201.A12 (GND), USB201.B1 (GND), USB201.B12 (GND), USB201.S1 (SHIELD), Y201.2, Y201.4
unnamed: C204.2, R208.1, Y201.1
unnamed: C403.1, R403.2
unnamed: D201.2 (A), R202.2
unnamed: D205.2 (A), R210.2
unnamed: D206.2 (A), R212.2
unnamed: D401.2 (A), L401.2, U401.1 (SW), U401.15 (SW), U401.16 (SW)
unnamed: C405.1, C406.1, C407.1, D401.1 (K), J401.1, J402.1, RV401.2
unnamed: D402.1 (K), R404.1
unnamed: D403.1 (K), R407.1
unnamed: J201.1, U203.24 (SWCLK)
unnamed: J201.2, U203.25 (SWD)
unnamed: J401.2, Q401.3 (D)
unnamed: J402.2, Q402.3 (D)
unnamed: R205.2, SW202.2
unnamed: R505.2, R506.1
unnamed: U202.6 (CLK), U203.52 (QSPI_SCLK)
unnamed: U202.5 (DI(IO0)), U203.53 (QSPI_SD0)
unnamed: U202.2 (DO(IO1)), U203.55 (QSPI_SD1)
unnamed: U202.3 (IO2), U203.54 (QSPI_SD2)
unnamed: U202.7 (IO3), U203.51 (QSPI_SD3)
unnamed: R205.1, U202.1 (~CS), U203.56 (QSPI_SS)
unnamed: R212.1, U203.36 (GPIO24)
unnamed: R210.1, U203.37 (GPIO25)
unnamed: R207.2, U203.46 (USB_DM)
unnamed: R206.2, U203.47 (USB_DP)
unnamed: C205.1, C206.1, C207.2, U203.23 (DVDD), U203.45 (VREG_VOUT), U203.50 (DVDD)
unnamed: C203.2, U203.20 (XIN), Y201.3
unnamed: R208.2, U203.21 (XOUT)
unnamed: R403.1, U401.7 (COMP)
unnamed: R405.1, RV401.3, U401.8 (FB)
unnamed: R402.1, U401.9 (FREQ)
unnamed: C401.1, U401.4 (SS)
unnamed: R501.1, R502.1, U501.1 (PS/SYNC), U501.14 (EN)
unnamed: R504.2, R505.1, U501.5 (FB)
unnamed: L501.1, U501.11 (L1)
unnamed: L501.2, U501.9 (L2)
unnamed: R503.2, U501.2 (PG)
unnamed: C504.1, U501.3 (VAUX)
unnamed: C505.1, C506.1, C507.1, C508.1, C509.1, C510.1, R503.1, R506.2, U501.7_8 (VOUT), U502.4 (VDD), U503.4 (VDD)
unnamed: R507.1, U502.5 (VOUT)
unnamed: R508.1, U503.5 (VOUT)
unnamed: R203.1, USB201.A5 (CC1)
unnamed: R204.1, USB201.B5 (CC2)
RCS_VIN: C402.1, C404.1, J101.1, L401.1, U401.2 (VIN)
RESET: D201.1 (K), R201.2, SW201.1, U203.26 (RUN)
VBUS: C101.1, D202.2 (A2), U101.3 (VI), USB201.A4 (VBUS), USB201.A9 (VBUS), USB201.B4 (VBUS), USB201.B9 (VBUS)
VDD: C102.1, C201.2, C202.2, C208.1, C209.2, C210.1, C211.1, C212.1, C213.1, C214.1, C215.1, C301.2, C501.1, C502.1, C503.1, C601.1, C602.1, C603.1, C604.1, C605.1, C606.1, C607.1, C608.1, C701.1, C702.1, C703.1, C704.1, J301.3, R201.1, R202.1, R209.1, R211.1, R501.2, U101.2 (VO), U201.3 (VCC), U202.8 (VCC), U203.1 (IOVDD), U203.10 (IOVDD), U203.22 (IOVDD), U203.33 (IOVDD), U203.42 (IOVDD), U203.43 (ADC_AVDD), U203.44 (VREG_IN), U203.48 (USB_VDD), U203.49 (IOVDD), U501.12_13 (VIN), U601.A1 (PS), U601.B2 (VDDIO), U601.E5 (VDD), U602.2 (ASDX), U602.3 (ASCX), U602.5 (VDDIO), U602.8 (VDD), U602.12 (CSB), U701.2 (CSB), U701.6 (VDDIO), U701.8 (VDD)

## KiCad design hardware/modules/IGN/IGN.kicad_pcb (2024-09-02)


Board: 2 copper layers, 60.0 x 60.0 mm, 79 parts (0 on the bottom side), 56 nets.

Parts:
BZ201: Buzzer; Buzzer_12x9.5RM7.6
C101, C102, C201: 10uF; C_0603_1608Metric
C202, C301, C302, C305, C306, C308, C310, C311, C312, C313, C314, C315, C401: 100nF; C_0402_1005Metric
C303, C304: 27pF; C_0402_1005Metric
C307, C309: 1uF; C_0402_1005Metric
D201: PMOS; LED_0805_2012Metric
D202, D204: D_Schottky; D_SOD-323
D203: ALERT; LED_0805_2012Metric
D205: NMOS; LED_0805_2012Metric
D206: NORMAL; LED_0805_2012Metric
D301: RESET; LED_0805_2012Metric
D302, D303, D304: 5V; D_SOD-882D
D305: STAT; LED_0805_2012Metric
D306: ERROR; LED_0805_2012Metric
F201: Polyfuse; Fuse_1206_3216Metric
J101: THERMISTER; JST_XH_B2B-XH-A_1x02_P2.50mm_Vertical
J201: IGNITER; JST_XH_S2B-XH-A_1x02_P2.50mm_Horizontal
J202: PowerSW; JST_XH_B2B-XH-A_1x02_P2.50mm_Vertical
J203: LiPo 1 Cell; JST_PH_B2B-PH-K_1x02_P2.00mm_Vertical
J301: DEBUG; PinHeader_1x03_P1.27mm_Vertical
J401: Jumper; PinHeader_1x02_P1.27mm_Vertical
J402: Conn_01x04_MountingPin; Grove_4P_L_SMD
Q201: Q_PMOS_GSD; TO-220F-3_Vertical
Q202: Q_NMOS_GSD; TO-220F-3_Vertical
Q203: Q_NPN_BEC; TO-220F-3_Vertical
R101, R202, R205, R206, R301, R309, R311: 10k; R_0402_1005Metric
R201, R208, R210, R211, R212, R302, R305, R308, R310, R312: 1k; R_0402_1005Metric
R203: 20mΩ; R_2010_5025Metric
R204: 1; R_2512_6332Metric
R207, R209: 510; R_0402_1005Metric
R303, R304: 5.1k; R_0402_1005Metric
R306, R307: 22.4; R_0402_1005Metric
R401: 120; R_0402_1005Metric
SW301: RESET_sw; TVAF06-A020B-R
SW302: BOOT0; TVAF06-A020B-R
U101: AMS1117-3.3; SOT-223-3_TabPin2
U201: INA226; VSSOP-10_3x3mm_P0.5mm
U301: SN65HVD230; SOIC-8_3.9x4.9mm_P1.27mm
U302: W25Q128JVS; SOIC-8_5.23x5.23mm_P1.27mm
U303: RP2040; QFN-56-1EP_7x7mm_P0.4mm_EP3.2x3.2mm
USB301: USB_C_Receptacle_USB2.0; USB_C_TYPEC-301S-ACP16X7
Y301: Crystal_GND24; Crystal_SMD_3225-4Pin_3.2x2.5mm

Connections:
/HIGH: R211.1, U303.4 (GPIO2)
/I2C_SCL: R311.2, U201.1 (A1), U201.5 (SCL), U303.28 (GPIO17)
/I2C_SDA: R309.2, U201.4 (SDA), U303.27 (GPIO16)
/IF/CANH: J402.1, R401.2, U301.6 (CANL)
/IF/CANL: J401.2, J402.2, U301.7 (CANH)
/LOW: R209.1, U303.3 (GPIO1)
/Normal: R212.1, U303.5 (GPIO3)
/RP2040core/CAN_RX: U301.4 (R), U303.35 (GPIO23)
/RP2040core/CAN_TX: U301.1 (D), U303.34 (GPIO22)
/RP2040core/GPIO26_ADC0: J101.2, R101.2, U303.38 (GPIO26_ADC0)
/RP2040core/USB_D+: D303.2 (A2), R306.1, USB301.A6 (D+), USB301.B6 (D+)
/RP2040core/USB_D-: D304.2 (A2), R307.1, USB301.A7 (D-), USB301.B7 (D-)
GND: BZ201.2 (-), C101.2, C102.2, C201.2, C202.2, C301.1, C302.1, C303.1, C304.1, C305.2, C306.2, C307.1, C308.2, C309.1, C310.2, C311.2, C312.2, C313.2, C314.2, C315.2, C401.1, D201.1 (K), D206.1 (K), D302.1 (A1), D303.1 (A1), D304.1 (A1), D305.1 (K), D306.1 (K), J101.1, J203.2, J301.3, J402.4, J402.MP (MountPin), Q202.3 (D), Q203.3 (E), R202.1, R206.1, R303.2, R304.2, SW301.2, SW302.1, U101.1 (GND), U201.7 (GND), U301.2 (GND), U301.8 (Rs), U302.4 (GND), U303.19 (TESTEN), U303.57 (GND), USB301.A1 (GND), USB301.A12 (GND), USB301.B1 (GND), USB301.B12 (GND), USB301.S1 (SHIELD), Y301.2, Y301.4
unnamed: BZ201.1 (+), Q201.3 (S), R201.1, R202.2, R203.2, R208.1, U201.8 (Vbus), U201.10 (Vin+)
unnamed: C304.2, R308.1, Y301.1
unnamed: D201.2 (A), R201.2
unnamed: D202.2 (A), D203.1 (K), R204.2
unnamed: D202.1 (K), D204.1 (K), Q202.2 (S)
unnamed: D203.2 (A), R208.2
unnamed: D204.2 (A), R210.2
unnamed: D205.1 (K), R210.1
unnamed: D206.2 (A), R212.2
unnamed: D301.2 (A), R302.2
unnamed: D305.2 (A), R310.2
unnamed: D306.2 (A), R312.2
unnamed: J201.1, R204.1
unnamed: J201.2, R203.1, U201.9 (Vin-)
unnamed: J202.1, J203.1
unnamed: F201.1, J202.2
unnamed: J301.1, U303.24 (SWCLK)
unnamed: J301.2, U303.25 (SWD)
unnamed: J401.1, R401.1
unnamed: F201.2, Q201.1 (D), R205.1
unnamed: Q201.2 (G), R205.2, R207.1
unnamed: Q202.1 (G), R206.2, R209.2
unnamed: Q203.2 (B), R211.2
unnamed: Q203.1 (C), R207.2
unnamed: R305.2, SW302.2
unnamed: U302.6 (CLK), U303.52 (QSPI_SCLK)
unnamed: U302.5 (DI(IO0)), U303.53 (QSPI_SD0)
unnamed: U302.2 (DO(IO1)), U303.55 (QSPI_SD1)
unnamed: U302.3 (IO2), U303.54 (QSPI_SD2)
unnamed: U302.7 (IO3), U303.51 (QSPI_SD3)
unnamed: R305.1, U302.1 (~CS), U303.56 (QSPI_SS)
unnamed: R312.1, U303.36 (GPIO24)
unnamed: R310.1, U303.37 (GPIO25)
unnamed: R307.2, U303.46 (USB_DM)
unnamed: R306.2, U303.47 (USB_DP)
unnamed: C305.1, C306.1, C307.2, U303.23 (DVDD), U303.45 (VREG_VOUT), U303.50 (DVDD)
unnamed: C303.2, U303.20 (XIN), Y301.3
unnamed: R308.2, U303.21 (XOUT)
unnamed: R303.1, USB301.A5 (CC1)
unnamed: R304.1, USB301.B5 (CC2)
RESET: D301.1 (K), R301.2, SW301.1, U303.26 (RUN)
VBUS: C101.1, D302.2 (A2), U101.3 (VI), USB301.A4 (VBUS), USB301.A9 (VBUS), USB301.B4 (VBUS), USB301.B9 (VBUS)
VDD: C102.1, C201.1, C202.1, C301.2, C302.2, C308.1, C309.2, C310.1, C311.1, C312.1, C313.1, C314.1, C315.1, C401.2, D205.2 (A), J402.3, R101.1, R301.1, R302.1, R309.1, R311.1, U101.2 (VO), U201.2 (A0), U201.6 (VS), U301.3 (VCC), U302.8 (VCC), U303.1 (IOVDD), U303.10 (IOVDD), U303.22 (IOVDD), U303.33 (IOVDD), U303.42 (IOVDD), U303.43 (ADC_AVDD), U303.44 (VREG_IN), U303.48 (USB_VDD), U303.49 (IOVDD)

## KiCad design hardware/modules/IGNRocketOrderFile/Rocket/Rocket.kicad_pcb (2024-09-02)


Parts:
BT201: Battery_Cell; cr1220

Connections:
+BATT: BT201.1 (+); also elsewhere on the board
GND: BT201.2 (-); also elsewhere on the board


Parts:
C601, C604: 10uF; C_0603_1608Metric; LCSC C96446
C602, C603: 100nF; C_0402_1005Metric; LCSC C1525
U601: BME280; LCSC C92489

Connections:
/I2C_SCL: U601.4 (SCK); also elsewhere on the board
/I2C_SDA: U601.3 (SDI); also elsewhere on the board
GND: C601.2, C602.2, C603.2, C604.2, U601.1 (GND), U601.5 (SDO), U601.7 (GND); also elsewhere on the board
VDD: C601.1, C602.1, C603.1, C604.1, U601.2 (CSB), U601.6 (VDDIO), U601.8 (VDD); also elsewhere on the board


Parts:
C501: 10uF; C_0603_1608Metric; LCSC C96446
C502: 100nF; C_0402_1005Metric; LCSC C1525
U501: E220-900T22S(JP)

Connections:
/AUX: U501.9 (AUX); also elsewhere on the board
/M0: U501.5 (M0); also elsewhere on the board
/M1: U501.6 (M1); also elsewhere on the board
/RTX0: U501.8 (TXD); also elsewhere on the board
/TRX0: U501.7 (RXD); also elsewhere on the board
GND: C501.2, C502.2, U501.1 (GND), U501.2 (GND), U501.3 (GND), U501.4 (GND), U501.11 (GND), U501.13 (GND), U501.19 (GND), U501.20 (GND), U501.22 (GND); also elsewhere on the board
VDD: C501.1, C502.1, U501.10 (VDD); also elsewhere on the board


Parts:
J701, J702: Conn_01x02; PinHeader_1x02_P1.27mm_Vertical
R701, R702: 470; R_0402_1005Metric; LCSC C25117
U701: SAM-M10Q; ublox_SAM-M8Q

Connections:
+BATT: U701.3 (V_BCKP); also elsewhere on the board
/GPS_RESET: U701.18 (~RESET); also elsewhere on the board
/RTX1: J702.2, R702.2; also elsewhere on the board
/TRX1: J701.2; also elsewhere on the board
/TimePulse: U701.7 (TIMEPULSE); also elsewhere on the board
GND: U701.1 (GND), U701.4 (GND), U701.5 (GND), U701.6 (GND), U701.10 (GND), U701.11 (GND), U701.15 (GND), U701.16 (GND), U701.20 (GND); also elsewhere on the board
unnamed: J701.1, J702.1, R701.2
unnamed: R701.1, U701.14 (RXD)
unnamed: R702.1, U701.13 (TXD)
VDD: U701.2 (VCC_IO), U701.17 (VCC); also elsewhere on the board


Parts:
C401, C402, C406, C407, C408, C411: 10uF; C_0603_1608Metric; LCSC C96446
C403, C409, C410, C415: 100nF; C_0402_1005Metric; LCSC C1525
C404, C405, C412, C413, C414: 22uF; C_0805_2012Metric; LCSC C45783
D401: D; D_SOD-323; LCSC C191023
F401, F402: Polyfuse; Fuse_1206_3216Metric; LCSC C883133
J401: Conn_01x03; PinHeader_1x03_P2.54mm_Vertical
J402: Ext Switch; JST_PH_S2B-PH-K_1x02_P2.00mm_Horizontal
J403: LiPo; JST_PH_S2B-PH-K_1x02_P2.00mm_Horizontal
L401: L; L_Wuerth_WE-TPC-3816; LCSC C3033018
LED401: USB Power; LED_0805_2012Metric; LCSC C2297
LED402: CHARGE; LED_0805_2012Metric; LCSC C2296
LED403: VDD; LED_0805_2012Metric; LCSC C2297
R401, R402, R404, R417: 1k; R_0402_1005Metric; LCSC C11702
R403: 4.7k; R_0402_1005Metric; LCSC C25900
R405, R406, R410: 10k; R_0402_1005Metric; LCSC C25744
R407, R408, R413: 100k; R_0402_1005Metric; LCSC C25741
R409, R412, R416: 50mΩ; R_0805_2012Metric; LCSC C247602
R411: 330k; R_0603_1608Metric; LCSC C23137
R414: 15k; R_0402_1005Metric; LCSC C25756
R415: 47k; R_0402_1005Metric; LCSC C25792
RV401: RV10k; Potentiometer_Bourns_TC33X_Vertical; LCSC C719176
U401: TPS2116DRL; SOT-583-8; LCSC C3235557
U402: MCP73871-1CC; QFN-20-1EP_4x4mm_P0.5mm_EP2.5x2.5mm; LCSC C511310
U403, U404, U406: INA226; VSSOP-10_3x3mm_P0.5mm; LCSC C49851
U405: TPS63070RNMR; VREG_TPS63070RNMR; LCSC C109322

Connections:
/CHARGE: R402.2; also elsewhere on the board
/DetL: J401.2; also elsewhere on the board
/I2C_SCL: U403.1 (A1), U403.5 (SCL), U404.1 (A1), U404.2 (A0), U404.5 (SCL), U406.1 (A1), U406.5 (SCL); also elsewhere on the board
/I2C_SDA: U403.4 (SDA), U404.4 (SDA), U406.2 (A0), U406.4 (SDA); also elsewhere on the board
/LiPoPower2/PROG: RV401.2, U402.13 (PROG1)
/PG: U402.6 (~PG); also elsewhere on the board
/ST: U401.8 (ST); also elsewhere on the board
/STAT1: U402.8 (STAT1/~LBO); also elsewhere on the board
/STAT2: U402.7 (STAT2); also elsewhere on the board
GND: C401.2, C402.2, C403.2, C404.2, C405.2, C406.2, C407.2, C408.2, C409.2, C410.2, C411.2, C412.2, C413.2, C414.2, C415.2, J401.3, J403.2, LED402.1 (K), R401.2, R403.1, R404.2, R406.2, R407.2, R411.2, R414.1, R417.2, U401.1 (GND), U402.9 (~TE), U402.10 (V_{SS}), U402.11 (V_{SS}), U402.21 (V_{SS}), U403.7 (GND), U404.7 (GND), U405.4 (GND), U405.10 (PGND), U405.15 (VSEL), U406.7 (GND); also elsewhere on the board
unnamed: D401.2 (A), J401.1
unnamed: J402.1, R410.1
unnamed: J402.2, R411.1, U403.3 (~Alert), U405.1 (PS/SYNC), U405.14 (EN), U406.3 (~Alert)
unnamed: F402.2, J403.1
unnamed: C401.1, F401.2, LED401.2 (A), R408.1, U402.2 (VPCC), U402.3 (SEL), U402.18 (IN), U402.19 (IN)
unnamed: LED401.1 (K), R401.1
unnamed: LED402.2 (A), R402.1
unnamed: LED403.1 (K), R417.1
unnamed: R404.1, RV401.3
unnamed: C402.1, C406.1, R405.1, U401.3 (VIN1), U401.5 (MODE), U402.1 (OUT), U402.20 (OUT)
unnamed: R403.2, R405.2, U401.4 (PR1)
unnamed: R408.2, U402.17 (CE), U404.3 (~Alert)
unnamed: R407.1, U402.12 (PROG3)
unnamed: R406.1, U402.5 (THERM)
unnamed: C407.1, R412.1, U402.14 (V_{BAT}), U402.15 (V_{BAT}), U402.16 (V_{BAT_SENSE}), U404.9 (Vin-)
unnamed: C404.1, C405.1, C408.1, R409.2, R410.2, U403.9 (Vin-), U405.12_13 (VIN)
unnamed: F402.1, R412.2, U404.8 (Vbus), U404.10 (Vin+)
unnamed: R414.2, R415.1, U405.5 (FB)
unnamed: L401.1, U405.11 (L1)
unnamed: L401.2, U405.9 (L2)
unnamed: R413.2, U405.2 (PG)
unnamed: C410.1, U405.3 (VAUX)
VBUS: C411.1, C412.1, C413.1, C414.1, C415.1, D401.1 (K), F401.1, R413.1, R415.2, R416.1, U405.7_8 (VOUT), U406.6 (VS), U406.8 (Vbus), U406.10 (Vin+); also elsewhere on the board
VDD: LED403.2 (A), R416.2, U406.9 (Vin-); also elsewhere on the board
VPP: C403.1, C409.1, R409.1, U401.2 (VOUT), U401.7 (VOUT), U403.2 (A0), U403.6 (VS), U403.8 (Vbus), U403.10 (Vin+), U404.6 (VS)

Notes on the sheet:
USB Bus Power ->
6V Max
I2C ADDR: 0x4E
I2C ADDR: 0x4F
I2C ADDR: 0x4D
-> 3.3V Output
<-> LiPo

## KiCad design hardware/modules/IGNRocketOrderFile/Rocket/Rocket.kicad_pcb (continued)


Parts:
C301, C303: 100nF; C_0402_1005Metric; LCSC C1525
C302: 10uF; C_0603_1608Metric; LCSC C96446
D301, D302, D304: 5V; D_SOD-882D; LCSC C7420372
D303: D; D_SOD-323; LCSC C191023
D305: RESET; LED_0805_2012Metric; LCSC C2296
D306: ERROR; LED_0805_2012Metric; LCSC C84256
D307: STAT; LED_0805_2012Metric; LCSC C2297
R301, R302: 5.1k; R_0402_1005Metric; LCSC C25905
R303, R304, R306: 470; R_0402_1005Metric; LCSC C25117
R305, R307: 10k; R_0402_1005Metric; LCSC C25744
SW301: RESET_sw; TVAF06-A020B-R
SW302: Boot_sw; TVAF06-A020B-R
U301: TPS3820; SOT-23-5; LCSC C7719
U302: ESP32-S3-WROOM-1
USB301: USB_C_Receptacle_USB2.0; USB_C_TYPEC-301S-ACP16X7; LCSC C2856766

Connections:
/AUX: U302.31 (GPIO38/FSPIWP/SUBSPIWP); also elsewhere on the board
/CHARGE: U302.22 (GPIO14/TOUCH14/ADC2_CH3/FSPIWP/FSPIDQS/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); also elsewhere on the board
/CLK: U302.39 (GPIO1/TOUCH1/ADC1_CH0); also elsewhere on the board
/DetL: U302.20 (GPIO12/TOUCH12/ADC2_CH1/FSPICLK/FSPIIO6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); also elsewhere on the board
/ESP32Core2/GPIO9/ADC1_CH8: U302.17 (GPIO9/TOUCH9/ADC1_CH8/FSPIHD/SUBSPIHD)
/ESP32Core2/GPIO10/ADC1_CH9: U302.18 (GPIO10/TOUCH10/ADC1_CH9/FSPICS0/FSPIIO4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)
/ESP32Core2/GPIO11: U302.19 (GPIO11/TOUCH11/ADC2_CH0/FSPID/FSPIIO5/S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)
/ESP32Core2/USB_D+: D302.2 (A2), U302.14 (GPIO20/U1CTS/ADC2_CH9/CLK_OUT1/USB_D+), USB301.A6 (D+), USB301.B6 (D+)
/ESP32Core2/USB_D-: D304.2 (A2), U302.13 (GPIO19/U1RTS/ADC2_CH8/CLK_OUT2/USB_D-), USB301.A7 (D-), USB301.B7 (D-)
/ESP32Core2/WDI: U301.4 (WDI), U302.8 (GPIO15/U0RTS/ADC2_CH4/XTAL_32K_P)
/GPS_RESET: U302.12 (GPIO8/TOUCH8/ADC1_CH7/SUBSPICS1); also elsewhere on the board
/I2C_SCL: R305.2, U302.9 (GPIO16/U0CTS/ADC2_CH5/XTAL_32K_N); also elsewhere on the board
/I2C_SDA: R307.2, U302.10 (GPIO17/U1TXD/ADC2_CH6); also elsewhere on the board
/M0: U302.33 (MTDO/GPIO40/CLK_OUT2); also elsewhere on the board
/M1: U302.32 (MTCK/GPIO39/CLK_OUT3/SUBSPICS1); also elsewhere on the board
/MISO: U302.15 (GPIO3/TOUCH3/ADC1_CH2); also elsewhere on the board
/MOSI: U302.4 (GPIO4/TOUCH4/ADC1_CH3); also elsewhere on the board
/PG: U302.23 (GPIO21); also elsewhere on the board
/RTX0: U302.36 (U0RXD/GPIO44/CLK_OUT2); also elsewhere on the board
/RTX1: U302.7 (GPIO7/TOUCH7/ADC1_CH6); also elsewhere on the board
/SD_DET: U302.5 (GPIO5/TOUCH5/ADC1_CH4); also elsewhere on the board
/SS: U302.38 (GPIO2/TOUCH2/ADC1_CH1); also elsewhere on the board
/ST: U302.21 (GPIO13/TOUCH13/ADC2_CH2/FSPIQ/FSPIIO7/S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); also elsewhere on the board
/STAT1: U302.24 (GPIO47/SPICLK_P/SUBSPICLK_P_DIFF); also elsewhere on the board
/STAT2: U302.25 (GPIO48/SPICLK_N/SUBSPICLK_N_DIFF); also elsewhere on the board
/TRX0: U302.37 (U0TXD/GPIO43/CLK_OUT1); also elsewhere on the board
/TRX1: U302.6 (GPIO6/TOUCH6/ADC1_CH5); also elsewhere on the board
/TimePulse: U302.11 (GPIO18/U1RXD/ADC2_CH7/CLK_OUT3); also elsewhere on the board
GND: C301.1, C302.1, C303.2, D301.1 (A1), D302.1 (A1), D304.1 (A1), D306.1 (K), D307.1 (K), R301.2, R302.2, SW301.2, SW302.2, U301.2 (GND), U302.1 (GND), U302.40 (GND), U302.41 (GND), USB301.A1 (GND), USB301.A12 (GND), USB301.B1 (GND), USB301.B12 (GND), USB301.S1 (SHIELD); also elsewhere on the board
unnamed: D301.2 (A2), D303.2 (A), USB301.A4 (VBUS), USB301.A9 (VBUS), USB301.B4 (VBUS), USB301.B9 (VBUS)
unnamed: D305.2 (A), R303.2
unnamed: D306.2 (A), R304.2
unnamed: D307.2 (A), R306.2
unnamed: SW301.1, U301.3 (MR)
unnamed: SW302.1, U302.27 (GPIO0/BOOT)
unnamed: R304.1, U302.34 (MTDI/GPIO41/CLK_OUT1)
unnamed: R306.1, U302.35 (MTMS/GPIO42)
unnamed: R301.1, USB301.A5 (CC1)
unnamed: R302.1, USB301.B5 (CC2)
RESET: D305.1 (K), U301.1 (RESET), U302.3 (EN)
VBUS: D303.1 (K); also elsewhere on the board
VDD: C301.2, C302.2, C303.1, R303.1, R305.1, R307.1, U301.5 (VDD), U302.2 (3V3); also elsewhere on the board

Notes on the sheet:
Pins: https://github.com/atomic14/esp32-s3-pinouts
Watchdog Timer & Reset
USB Type-C Connector
CC pin 56kΩ for 0.5A 22kΩ for 1.5A 10kΩ for 3.0A
ESP32 S3


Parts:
C901: 10uF; C_0603_1608Metric; LCSC C96446
C902: 100nF; C_0402_1005Metric; LCSC C1525
D901, D902: D; D_SOD-323; LCSC C191023
MICRO_SD901: TF-01A; LCSC C5155563
U901: PCF8563T; SOIC-8_3.9x4.9mm_P1.27mm; LCSC C7440
Y901: Crystal; Crystal_SMD_3215-2Pin_3.2x1.5mm; LCSC C32346

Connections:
+BATT: D901.2 (A); also elsewhere on the board
/CLK: MICRO_SD901.5 (CLK); also elsewhere on the board
/I2C_SCL: U901.6 (SCL); also elsewhere on the board
/I2C_SDA: U901.5 (SDA); also elsewhere on the board
/MISO: MICRO_SD901.7 (DAT0); also elsewhere on the board
/MOSI: MICRO_SD901.3 (CMD); also elsewhere on the board
/SD_DET: MICRO_SD901.CD1 (CD); also elsewhere on the board
/SS: MICRO_SD901.2 (CD/DAT3); also elsewhere on the board
GND: C901.2, C902.1, MICRO_SD901.6 (VSS), MICRO_SD901.MP1 (SHIELD), MICRO_SD901.MP2 (SHIELD), MICRO_SD901.MP3 (SHIELD), MICRO_SD901.MP4 (SHIELD), U901.4 (VSS); also elsewhere on the board
unnamed: C902.2, D901.1 (K), D902.1 (K), U901.8 (VDD)
unnamed: U901.1 (OSCI), Y901.1
unnamed: U901.2 (OSCO), Y901.2
VDD: C901.1, D902.2 (A), MICRO_SD901.4 (VDD); also elsewhere on the board

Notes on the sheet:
RTC
Micro SD Card Slot
I2C ADDR: 0x51


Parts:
C801, C802, C807: 100nF; C_0402_1005Metric; LCSC C1525
C803, C804, C808: 10uF; C_0603_1608Metric; LCSC C96446
C805: 0.22uF; C_0402_1005Metric; LCSC C16772
C806: 4.7uF; C_0603_1608Metric; LCSC C19666
R801: 4.7k; R_0402_1005Metric; LCSC C25900
U801: BMI088; Manufacturer_Part_Number BMI088; LCSC C194919
U802: QMC5883L; _HMC5883L; LCSC C976032

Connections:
/I2C_SCL: U801.8 (SCL/SCK), U802.1 (SCL); also elsewhere on the board
/I2C_SDA: U801.9 (SDA/SDI), U802.16 (SDA); also elsewhere on the board
GND: C801.2, C802.2, C803.2, C804.2, C806.2, C807.2, C808.2, U801.2 (NC), U801.4 (GNDA), U801.6 (GNDIO), U802.9 (GND), U802.11 (GND); also elsewhere on the board
unnamed: R801.1, U801.10 (SDO2), U801.15 (SDO1)
unnamed: C806.1, U802.10 (C1)
unnamed: C805.1, U802.12 (SETC)
unnamed: C805.2, U802.8 (STEP)
VDD: C801.1, C802.1, C803.1, C804.1, C807.1, C808.1, R801.2, U801.3 (VDD), U801.7 (PS), U801.11 (VDDIO), U802.2 (VDD), U802.4 (S1), U802.13 (VDDIO); also elsewhere on the board



Board: 2 copper layers, 35.0 x 107.0 mm, 103 parts (3 on the bottom side), 74 nets.

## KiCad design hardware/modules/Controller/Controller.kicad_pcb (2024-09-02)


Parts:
C101, C102: 10u; C_0603_1608Metric; LCSC C96446
U101: AMS1117-3.3; SOT-223-3_TabPin2; LCSC C6186

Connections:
GND: C101.2, C102.2, U101.1 (GND); also elsewhere on the board
VBUS: C101.1, U101.3 (VI); also elsewhere on the board
VDD: C102.1, U101.2 (VO); also elsewhere on the board


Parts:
D107, D108, D109, D110, D111, D112, D113, D114, D115, D116, D117, D118, D119, D120: LED; LED_D3.0mm_FlatTop
J102: Conn_01x04_MountingPin; Grove_4P_L_SMD
R113, R119, R120, R121, R122, R123, R124, R125, R126, R127, R128: 47k; C_0402_1005Metric; LCSC C25792
R114, R115, R116, R117, R118: 1k; C_0402_1005Metric; LCSC C11702
SW103, SW105, SW106, SW107, SW108, SW109, SW110: sw1; ToggleSwitch
SW104: RotarySwitch_2x04
lcd101: SC2004CSWB-XA-LB-G; SC2004CSWB

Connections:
/DB4: lcd101.11 (DB4); also elsewhere on the board
/DB5: lcd101.12 (DB5); also elsewhere on the board
/DB6: lcd101.13 (DB6); also elsewhere on the board
/DB7: lcd101.14 (DB7); also elsewhere on the board
/E: lcd101.6 (E); also elsewhere on the board
/Go: J102.1, R122.2, SW104.5; also elsewhere on the board
/LoRa1sw: R125.2, SW107.2 (B); also elsewhere on the board
/LoRa2sw: R126.2, SW108.2 (B); also elsewhere on the board
/LoRa3sw: R127.2, SW105.2 (B); also elsewhere on the board
/LoRa4sw: R128.2, SW106.2 (B); also elsewhere on the board
/NoGo: J102.3, R119.2, SW104.2; also elsewhere on the board
/RS: lcd101.4 (RS); also elsewhere on the board
/abort: J102.2, R121.2, SW104.4; also elsewhere on the board
/col1: R118.1; also elsewhere on the board
/col2: R117.1; also elsewhere on the board
/col3: R116.1; also elsewhere on the board
/col4: R115.1; also elsewhere on the board
/lcd_sw1: R123.2, SW110.2 (B); also elsewhere on the board
/lcd_sw2: R124.2, SW109.2 (B); also elsewhere on the board
/raw1: D112.1 (K), D116.1 (K), D120.1 (K); also elsewhere on the board
/raw2: D110.1 (K), D114.1 (K), D118.1 (K); also elsewhere on the board
/raw3: D108.1 (K), D111.1 (K), D115.1 (K), D119.1 (K); also elsewhere on the board
/raw4: D107.1 (K), D109.1 (K), D113.1 (K), D117.1 (K); also elsewhere on the board
/sub: R120.2, SW104.3; also elsewhere on the board
GND: J102.4, J102.MP (MountPin), R114.1, SW103.3 (C), SW104.1, SW105.3 (C), SW106.3 (C), SW107.3 (C), SW108.3 (C), SW109.3 (C), SW110.3 (C), lcd101.1 (VSS), lcd101.5 (R/W); also elsewhere on the board
unnamed: D107.2 (A), D108.2 (A), R115.2
unnamed: D109.2 (A), D110.2 (A), D111.2 (A), D112.2 (A), R116.2
unnamed: D113.2 (A), D114.2 (A), D115.2 (A), D116.2 (A), R117.2
unnamed: D117.2 (A), D118.2 (A), D119.2 (A), D120.2 (A), R118.2
unnamed: R113.1, SW103.2 (B)
unnamed: R113.2, lcd101.17 (K)
unnamed: R114.2, lcd101.3 (Vo)
VDD: R119.1, R120.1, R121.1, R122.1, R123.1, R124.1, R125.1, R126.1, R127.1, R128.1, lcd101.2 (VDD), lcd101.15 (A); also elsewhere on the board


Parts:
C103, C104, C107, C108, C110, C112, C113, C114, C115, C116, C117: 100nF; C_0402_1005Metric; LCSC C1525
C105, C106: 27pF; C_0402_1005Metric; LCSC C1555
C109, C111: 1uF; C_0402_1005Metric; LCSC C52923
D101: RESET; LED_0805_2012Metric; LCSC C2296
D102, D103, D104: 5V; D_SOD-882; LCSC C7420372
D105: STAT; LED_0805_2012Metric; LCSC C2297
D106: ERROR; LED_0805_2012Metric; LCSC C84256
J101: DEBUG; PinHeader_1x03_P1.27mm_Vertical
R101, R109, R111: 10k; R_0402_1005Metric; LCSC C25744
R102, R105, R108, R110, R112: 1k; R_0402_1005Metric; LCSC C11702
R103, R104: 22k; R_0402_1005Metric; LCSC C25768
R106, R107: 22.4; R_0402_1005Metric; LCSC C25092
SW101: RESET_sw; TVAF06-A020B-R
SW102: BOOT0; TVAF06-A020B-R
U102: SN65HVD230; SOIC-8_3.9x4.9mm_P1.27mm; LCSC C12084
U103: W25Q128JVS; SOIC-8_5.23x5.23mm_P1.27mm; LCSC C97521
U104: RP2040; QFN-56-1EP_7x7mm_P0.4mm_EP3.2x3.2mm; LCSC C2040
USB101: USB_C_Receptacle_USB2.0; USB_C_TYPEC-301S-ACP16X7; LCSC C2856766
Y101: Crystal_GND24; Crystal_SMD_3225-4Pin_3.2x2.5mm; LCSC C9002

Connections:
/DB4: U104.11 (GPIO8); also elsewhere on the board
/DB5: U104.12 (GPIO9); also elsewhere on the board
/DB6: U104.13 (GPIO10); also elsewhere on the board
/DB7: U104.14 (GPIO11); also elsewhere on the board
/E: U104.9 (GPIO7); also elsewhere on the board
/Go: U104.5 (GPIO3); also elsewhere on the board
/LoRa1sw: U104.18 (GPIO15); also elsewhere on the board
/LoRa2sw: U104.17 (GPIO14); also elsewhere on the board
/LoRa3sw: U104.16 (GPIO13); also elsewhere on the board
/LoRa4sw: U104.15 (GPIO12); also elsewhere on the board
/ModuleIF/CANH: U102.7 (CANH); also elsewhere on the board
/ModuleIF/CANL: U102.6 (CANL); also elsewhere on the board
/NoGo: U104.2 (GPIO0); also elsewhere on the board
/RP2040/CAN_RX: U102.4 (R), U104.35 (GPIO23)
/RP2040/CAN_TX: U102.1 (D), U104.34 (GPIO22)
/RP2040/I2C_SCL: R111.2, U104.28 (GPIO17)
/RP2040/I2C_SDA: R109.2, U104.27 (GPIO16)
/RP2040/USB_D+: D103.2 (A2), R106.1, USB101.A6 (D+), USB101.B6 (D+)
/RP2040/USB_D-: D104.2 (A2), R107.1, USB101.A7 (D-), USB101.B7 (D-)
/RS: U104.6 (GPIO4); also elsewhere on the board
/abort: U104.4 (GPIO2); also elsewhere on the board
/col1: U104.38 (GPIO26_ADC0); also elsewhere on the board
/col2: U104.39 (GPIO27_ADC1); also elsewhere on the board
/col3: U104.40 (GPIO28_ADC2); also elsewhere on the board
/col4: U104.41 (GPIO29_ADC3); also elsewhere on the board
/lcd_sw1: U104.32 (GPIO21); also elsewhere on the board
/lcd_sw2: U104.31 (GPIO20); also elsewhere on the board
/raw1: U104.7 (GPIO5); also elsewhere on the board
/raw2: U104.8 (GPIO6); also elsewhere on the board
/raw3: U104.29 (GPIO18); also elsewhere on the board
/raw4: U104.30 (GPIO19); also elsewhere on the board
/sub: U104.3 (GPIO1); also elsewhere on the board
GND: C103.1, C104.1, C105.1, C106.1, C107.2, C108.2, C109.1, C110.2, C111.1, C112.2, C113.2, C114.2, C115.2, C116.2, C117.2, D102.1 (A1), D103.1 (A1), D104.1 (A1), D105.1 (K), D106.1 (K), J101.3, R103.2, R104.2, SW101.2, SW102.1, U102.2 (GND), U102.8 (Rs), U103.4 (GND), U104.19 (TESTEN), U104.57 (GND), USB101.A1 (GND), USB101.A12 (GND), USB101.B1 (GND), USB101.B12 (GND), USB101.S1 (SHIELD), Y101.2, Y101.4; also elsewhere on the board
unnamed: C106.2, R108.1, Y101.1
unnamed: D101.2 (A), R102.2
unnamed: D105.2 (A), R110.2
unnamed: D106.2 (A), R112.2
unnamed: J101.1, U104.24 (SWCLK)
unnamed: J101.2, U104.25 (SWD)
unnamed: R105.2, SW102.2
unnamed: U103.6 (CLK), U104.52 (QSPI_SCLK)
unnamed: U103.5 (DI(IO0)), U104.53 (QSPI_SD0)
unnamed: U103.2 (DO(IO1)), U104.55 (QSPI_SD1)
unnamed: U103.3 (IO2), U104.54 (QSPI_SD2)
unnamed: U103.7 (IO3), U104.51 (QSPI_SD3)
unnamed: R105.1, U103.1 (~CS), U104.56 (QSPI_SS)
unnamed: R112.1, U104.36 (GPIO24)
unnamed: R110.1, U104.37 (GPIO25)
unnamed: R107.2, U104.46 (USB_DM)
unnamed: R106.2, U104.47 (USB_DP)
unnamed: C107.1, C108.1, C109.2, U104.23 (DVDD), U104.45 (VREG_VOUT), U104.50 (DVDD)
unnamed: C105.2, U104.20 (XIN), Y101.3
unnamed: R108.2, U104.21 (XOUT)
unnamed: R103.1, USB101.A5 (CC1)
unnamed: R104.1, USB101.B5 (CC2)
RESET: D101.1 (K), R101.2, SW101.1, U104.26 (RUN)
VBUS: D102.2 (A2), USB101.A4 (VBUS), USB101.A9 (VBUS), USB101.B4 (VBUS), USB101.B9 (VBUS); also elsewhere on the board
VDD: C103.2, C104.2, C110.1, C111.2, C112.1, C113.1, C114.1, C115.1, C116.1, C117.1, R101.1, R102.1, R109.1, R111.1, U102.3 (VCC), U103.8 (VCC), U104.1 (IOVDD), U104.10 (IOVDD), U104.22 (IOVDD), U104.33 (IOVDD), U104.42 (IOVDD), U104.43 (ADC_AVDD), U104.44 (VREG_IN), U104.48 (USB_VDD), U104.49 (IOVDD); also elsewhere on the board

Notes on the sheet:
CAN Tranceiver
USB Type-C Connector
CC pin 56kΩ for 0.5A 22kΩ for 1.5A 10kΩ for 3.0A


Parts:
C118: 100nF; C_0402_1005Metric; LCSC C1525
J103: Jumper; PinHeader_1x02_P1.27mm_Vertical
J104: Conn_01x04_MountingPin; Grove_4P_L_SMD
R129: 120; R_0402_1005Metric; LCSC C25079

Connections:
/ModuleIF/CANH: J104.1, R129.2; also elsewhere on the board
/ModuleIF/CANL: J103.2, J104.2; also elsewhere on the board
GND: C118.1, J104.4, J104.MP (MountPin); also elsewhere on the board
unnamed: J103.1, R129.1
VDD: C118.2, J104.3; also elsewhere on the board



Board: 2 copper layers, 120.0 x 72.0 mm, 88 parts (2 on the bottom side), 66 nets.

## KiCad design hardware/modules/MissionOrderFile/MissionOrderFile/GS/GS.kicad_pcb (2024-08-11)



Board: 2 copper layers, 60.0 x 60.0 mm, 88 parts (2 on the bottom side), 70 nets.

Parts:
AE301: Antenna; GNSS_Antenna_1212
BT101: Battery; cr1220
C101, C203, C601, C602, C603, C606, C607, C610, C701: 10uF; C_0603_1608Metric
C201, C202, C204, C301, C401, C501, C608, C609, C702: 100nF; C_0402_1005Metric
C604, C605, C611, C612, C613: 10uF; C_0805_2012Metric
D201, D202, D203: 5V; D_SOD-882
D204: RESET; LED_0805_2012Metric
D205: ERROR; LED_0805_2012Metric
D206: STAT; LED_0805_2012Metric
F601, F602, F603: Polyfuse; Fuse_1206_3216Metric
J401, J501: Jumper; PinHeader_1x02_P1.27mm_Vertical
J402, J502: Conn_01x04_MountingPin; Grove_4P_L_SMD
J601: Battery; JST_XH_S2B-XH-A_1x02_P2.50mm_Horizontal
J602: LiPo; JST_PH_S2B-PH-K_1x02_P2.00mm_Horizontal
L601: L; L_Wuerth_WE-TPC-3816
LED601: USB Power; LED_0805_2012Metric
LED602: Backup; LED_0805_2012Metric
LED603: CHARGE; LED_0805_2012Metric
LED604: VDD; LED_0805_2012Metric
MICRO_SD701: TF-01A
R201, R202: 5.1k; R_0402_1005Metric
R203, R204, R206: 470; R_0402_1005Metric
R205, R207, R604, R609: 10k; R_0402_1005Metric
R301, R302: 33; R_0402_1005Metric
R401, R501: 120; R_0402_1005Metric
R601, R602, R608, R610, R616: 1k; R_0402_1005Metric
R603, R606, R607, R611, R613: 100k; R_0402_1005Metric
R605, R615: 47k; R_0402_1005Metric
R612: 50mΩ; R_0805_2012Metric
R614: 15k; R_0402_1005Metric
RV601: 10k; Potentiometer_Bourns_TC33X_Vertical
SW201, SW202: RESET_sw; TVAF06-A020B-R
SW601: Power Switch; SW_Slide_SPDT_Angled_CK_OS102011MA1Q
U201: TPS3820; SOT-23-5
U202: SN65HVD230; SOIC-8_3.9x4.9mm_P1.27mm
U203: ESP32-S3-WROOM-1
U301: NEO-M9N-00B; ATGM332D-5N31
U601: MCP73871-1CC; QFN-20-1EP_4x4mm_P0.5mm_EP2.5x2.5mm
U602: TPS2116DRL; SOT-583-8
U603: TPS63070RNMR; VREG_TPS63070RNMR
U604: INA226; VSSOP-10_3x3mm_P0.5mm
U701: PCF8563T; SOIC-8_3.9x4.9mm_P1.27mm
USB201: USB_C_Receptacle_USB2.0; USB_C_TYPEC-301S-ACP16X7
Y701: Crystal; Crystal_SMD_3215-2Pin_3.2x1.5mm

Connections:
+BATT: C702.2, U701.8 (VDD)
/CLK: MICRO_SD701.5 (CLK), U203.20 (GPIO12/TOUCH12/ADC2_CH1/FSPICLK/FSPIIO6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)
/DET: MICRO_SD701.CD1 (CD), U203.17 (GPIO9/TOUCH9/ADC1_CH8/FSPIHD/SUBSPIHD)
/ESP32/CANH: J402.1, J502.1, R401.2, R501.2, U202.7 (CANH)
/ESP32/CANL: J401.2, J402.2, J501.2, J502.2, U202.6 (CANL)
/ESP32/CAN_RX: U202.4 (R), U203.36 (U0RXD/GPIO44/CLK_OUT2)
/ESP32/CAN_TX: U202.1 (D), U203.37 (U0TXD/GPIO43/CLK_OUT1)
/ESP32/GPIO1/ADC1_CH0: R301.1, U203.39 (GPIO1/TOUCH1/ADC1_CH0)
/ESP32/GPIO2/ADC1_CH1: R302.1, U203.38 (GPIO2/TOUCH2/ADC1_CH1)
/ESP32/GPIO18: R608.2, U203.11 (GPIO18/U1RXD/ADC2_CH7/CLK_OUT3), U602.8 (ST)
/ESP32/GPIO38: U203.31 (GPIO38/FSPIWP/SUBSPIWP), U301.8 (RESET_N)
/ESP32/GPIO39: U203.32 (MTCK/GPIO39/CLK_OUT3/SUBSPICS1), U301.3 (TIMEPULSE)
/ESP32/GPIO40: R610.2, U203.33 (MTDO/GPIO40/CLK_OUT2)
/ESP32/USB_D+: D202.2 (A2), U203.14 (GPIO20/U1CTS/ADC2_CH9/CLK_OUT1/USB_D+), USB201.A6 (D+), USB201.B6 (D+)
/ESP32/USB_D-: D203.2 (A2), U203.13 (GPIO19/U1RTS/ADC2_CH8/CLK_OUT2/USB_D-), USB201.A7 (D-), USB201.B7 (D-)
/ESP32/VUSB: D201.2 (A2), F601.1, USB201.A4 (VBUS), USB201.A9 (VBUS), USB201.B4 (VBUS), USB201.B9 (VBUS)
/ESP32/WDI: U201.4 (WDI), U203.8 (GPIO15/U0RTS/ADC2_CH4/XTAL_32K_P)
/GPS/+BATT: BT101.1 (+), C101.2, U301.22 (V_BCKP)
/MISO: MICRO_SD701.7 (DAT0), U203.21 (GPIO13/TOUCH13/ADC2_CH2/FSPIQ/FSPIIO7/S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)
/MOSI: MICRO_SD701.3 (CMD), U203.19 (GPIO11/TOUCH11/ADC2_CH0/FSPID/FSPIIO5/S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)
/PG: U203.23 (GPIO21), U601.6 (~PG)
/SCL: R205.2, U203.9 (GPIO16/U0CTS/ADC2_CH5/XTAL_32K_N), U604.1 (A1), U604.2 (A0), U604.5 (SCL), U701.6 (SCL)
/SDA: R207.2, U203.10 (GPIO17/U1TXD/ADC2_CH6), U604.4 (SDA), U701.5 (SDA)
/SS: MICRO_SD701.2 (CD/DAT3), U203.18 (GPIO10/TOUCH10/ADC1_CH9/FSPICS0/FSPIIO4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)
/STAT1: U203.25 (GPIO48/SPICLK_N/SUBSPICLK_N_DIFF), U601.8 (STAT1/~LBO)
/STAT2: U203.24 (GPIO47/SPICLK_P/SUBSPICLK_P_DIFF), U601.7 (STAT2)
GND: BT101.2 (-), C101.1, C201.1, C202.1, C203.1, C204.2, C301.1, C401.1, C501.1, C601.2, C602.2, C603.2, C604.2, C605.2, C606.2, C607.2, C608.2, C609.2, C610.2, C611.2, C612.2, C613.2, C701.2, C702.1, D201.1 (A1), D202.1 (A1), D203.1 (A1), D205.1 (K), D206.1 (K), J402.4, J402.MP (MountPin), J502.4, J502.MP (MountPin), J601.2, J602.2, LED603.1 (K), MICRO_SD701.6 (VSS), MICRO_SD701.MP1 (SHIELD), MICRO_SD701.MP2 (SHIELD), MICRO_SD701.MP3 (SHIELD), MICRO_SD701.MP4 (SHIELD), R201.2, R202.2, R601.2, R602.2, R603.2, R604.1, R605.1, R611.2, R614.1, R616.2, SW201.2, SW202.2, U201.2 (GND), U202.2 (GND), U202.8 (Rs), U203.1 (GND), U203.40 (GND), U203.41 (GND), U301.10 (GND), U301.12 (GND), U301.13 (GND), U301.24 (GND), U601.9 (~TE), U601.10 (V_{SS}), U601.11 (V_{SS}), U601.21 (V_{SS}), U602.1 (GND), U603.4 (GND), U603.10 (PGND), U603.15 (VSEL), U604.7 (GND), U701.4 (VSS), USB201.A1 (GND), USB201.A12 (GND), USB201.B1 (GND), USB201.B12 (GND), USB201.S1 (SHIELD)
GPSANT1: AE301.1 (A), U301.11 (RF_IN)
unnamed: D204.2 (A), R203.2
unnamed: D205.2 (A), R204.2
unnamed: D206.2 (A), R206.2
unnamed: J401.1, R401.1
unnamed: J501.1, R501.1
unnamed: F602.1, J601.1
unnamed: F603.2, J602.1
unnamed: C601.1, F601.2, LED601.2 (A), R606.1, U601.2 (VPCC), U601.3 (SEL), U601.18 (IN), U601.19 (IN)
unnamed: LED601.1 (K), R601.1
unnamed: C604.1, C605.1, C607.1, C608.1, LED602.2 (A), R609.1, U602.2 (VOUT), U602.7 (VOUT), U603.12_13 (VIN), U604.6 (VS)
unnamed: LED602.1 (K), R608.1
unnamed: LED603.2 (A), R610.1
unnamed: LED604.1 (K), R616.1
unnamed: R602.1, RV601.3
unnamed: R609.2, SW601.2 (B)
unnamed: R611.1, SW601.3 (C), U603.1 (PS/SYNC), U603.14 (EN)
unnamed: SW201.1, U201.3 (MR)
unnamed: SW202.1, U203.27 (GPIO0/BOOT)
unnamed: R204.1, U203.34 (MTDI/GPIO41/CLK_OUT1)
unnamed: R206.1, U203.35 (MTMS/GPIO42)
unnamed: R301.2, U301.21 (RXD_/_SPI_MOSI)
unnamed: R302.2, U301.20 (TXD_/_SPI_MISO)
unnamed: R606.2, U601.17 (CE), U604.3 (~Alert)
unnamed: RV601.2, U601.13 (PROG1)
unnamed: R603.1, U601.12 (PROG3)
unnamed: R604.2, U601.5 (THERM)
unnamed: C606.1, R612.1, U601.14 (V_{BAT}), U601.15 (V_{BAT}), U601.16 (V_{BAT_SENSE}), U604.9 (Vin-)
unnamed: C603.1, R607.1, U601.1 (OUT), U601.20 (OUT), U602.3 (VIN1), U602.5 (MODE)
unnamed: R605.2, R607.2, U602.4 (PR1)
unnamed: C602.1, F602.2, U602.6 (VIN2)
unnamed: R614.2, R615.1, U603.5 (FB)
unnamed: L601.1, U603.11 (L1)
unnamed: L601.2, U603.9 (L2)
unnamed: R613.2, U603.2 (PG)
unnamed: C609.1, U603.3 (VAUX)
unnamed: F603.1, R612.2, U604.8 (Vbus), U604.10 (Vin+)
unnamed: U701.1 (OSCI), Y701.1
unnamed: U701.2 (OSCO), Y701.2
unnamed: R201.1, USB201.A5 (CC1)
unnamed: R202.1, USB201.B5 (CC2)
RESET: D204.1 (K), U201.1 (RESET), U203.3 (EN)
VDD: C201.2, C202.2, C203.2, C204.1, C301.2, C401.2, C501.2, C610.1, C611.1, C612.1, C613.1, C701.1, J402.3, J502.3, LED604.2 (A), MICRO_SD701.4 (VDD), R203.1, R205.1, R207.1, R613.1, R615.2, U201.5 (VDD), U202.3 (VCC), U203.2 (3V3), U301.7 (V_USB), U301.23 (VCC), U603.7_8 (VOUT)

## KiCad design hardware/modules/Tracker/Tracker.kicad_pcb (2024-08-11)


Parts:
BT101: Battery_Cell; cr1220

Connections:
/GPSActive/+BATT: BT101.1 (+); also elsewhere on the board
GND: BT101.2 (-); also elsewhere on the board


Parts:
C501, C502: 100nF; C_0402_1005Metric; LCSC C1525
C503: 100nF; C_0402_1005Metric
D501, D502, D503: 5V; D_SOD-882D; LCSC C7420372
J501: SMA; SMA_Amphenol_132203-12_Horizontal; LCSC C2693813
L501: 27nH, 300mA; L_0402_1005Metric
R501, R502: 5.1k; R_0402_1005Metric; LCSC C25905
R503: 10; R_0402_1005Metric; LCSC C25077
R504, R505: 33; R_0402_1005Metric; LCSC C25105
U501: NEO-M9N-00B; ATGM332D-5N31
USB501: USB_C_Receptacle_USB2.0; USB_C_TYPEC-301S-ACP16X7; LCSC C2982481

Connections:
/ESP32/GPIO18: U501.3 (TIMEPULSE); also elsewhere on the board
/ESP32/GPIO21: U501.8 (RESET_N); also elsewhere on the board
/ESP32/GPIO47: R505.1; also elsewhere on the board
/ESP32/GPIO48: R504.1; also elsewhere on the board
/GPSActive/+BATT: C503.2, U501.22 (V_BCKP); also elsewhere on the board
/GPSActive/USB_D+: D502.2 (A2), U501.6 (USB_DP), USB501.A6 (D+), USB501.B6 (D+)
/GPSActive/USB_D-: D503.2 (A2), U501.5 (USB_DM), USB501.A7 (D-), USB501.B7 (D-)
GND: C501.2, C502.1, C503.1, D501.1 (A1), D502.1 (A1), D503.1 (A1), J501.2 (Ext), R501.2, R502.2, U501.10 (GND), U501.12 (GND), U501.13 (GND), U501.24 (GND), USB501.A1 (GND), USB501.A12 (GND), USB501.B1 (GND), USB501.B12 (GND), USB501.S1 (SHIELD); also elsewhere on the board
GPSANT1: J501.1 (In), L501.1, U501.11 (RF_IN)
unnamed: C501.1, L501.2, R503.2
unnamed: D501.2 (A2), USB501.A4 (VBUS), USB501.A9 (VBUS), USB501.B4 (VBUS), USB501.B9 (VBUS)
unnamed: R504.2, U501.21 (RXD_/_SPI_MOSI)
unnamed: R505.2, U501.20 (TXD_/_SPI_MISO)
unnamed: R501.1, USB501.A5 (CC1)
unnamed: R502.1, USB501.B5 (CC2)
VCCRF: R503.1, U501.9 (VCC_RF)
VDD: C502.2, U501.7 (V_USB), U501.23 (VCC); also elsewhere on the board

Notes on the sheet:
CC pin 56kΩ for 0.5A 22kΩ for 1.5A 10kΩ for 3.0A
USB Type-C Connector


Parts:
C601, C603: 100nF; C_0402_1005Metric; LCSC C1525
C602: 10uF; C_0603_1608Metric; LCSC C96446
D601, D602, D603: 5V; D_SOD-882D; LCSC C7420372
D604: RESET; LED_0805_2012Metric; LCSC C2296
D605: ERROR; LED_0805_2012Metric; LCSC C84256
D606: STAT; LED_0805_2012Metric; LCSC C2297
R601, R602: 5.1k; R_0402_1005Metric; LCSC C25905
R603, R604, R606: 470; R_0402_1005Metric; LCSC C25117
R605, R607: 10k; R_0402_1005Metric; LCSC C25744
SW101, SW601: RESET; TVAF06-A020B-R
U601: TPS3820; SOT_23_5; LCSC C130064
U602: ESP32-S3-WROOM-1
USB601: USB_C_Receptacle_USB2.0; USB_C_TYPEC-301S-ACP16X7; LCSC C2982481

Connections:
/ESP32/CAN_RX: U602.36 (U0RXD/GPIO44/CLK_OUT2); also elsewhere on the board
/ESP32/CAN_TX: U602.37 (U0TXD/GPIO43/CLK_OUT1); also elsewhere on the board
/ESP32/GPIO1/ADC1_CH0: U602.39 (GPIO1/TOUCH1/ADC1_CH0); also elsewhere on the board
/ESP32/GPIO2/ADC1_CH1: U602.38 (GPIO2/TOUCH2/ADC1_CH1); also elsewhere on the board
/ESP32/GPIO3/ADC1_CH2: U602.15 (GPIO3/TOUCH3/ADC1_CH2); also elsewhere on the board
/ESP32/GPIO4/ADC1_CH3: U602.4 (GPIO4/TOUCH4/ADC1_CH3); also elsewhere on the board
/ESP32/GPIO5/ADC1_CH4: U602.5 (GPIO5/TOUCH5/ADC1_CH4); also elsewhere on the board
/ESP32/GPIO6/ADC1_CH5: U602.6 (GPIO6/TOUCH6/ADC1_CH5); also elsewhere on the board
/ESP32/GPIO7/ADC1_CH6: U602.7 (GPIO7/TOUCH7/ADC1_CH6); also elsewhere on the board
/ESP32/GPIO8/ADC1_CH7: U602.12 (GPIO8/TOUCH8/ADC1_CH7/SUBSPICS1); also elsewhere on the board
/ESP32/GPIO9/ADC1_CH8: U602.17 (GPIO9/TOUCH9/ADC1_CH8/FSPIHD/SUBSPIHD); also elsewhere on the board
/ESP32/GPIO10/ADC1_CH9: U602.18 (GPIO10/TOUCH10/ADC1_CH9/FSPICS0/FSPIIO4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); also elsewhere on the board
/ESP32/GPIO11: U602.19 (GPIO11/TOUCH11/ADC2_CH0/FSPID/FSPIIO5/S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); also elsewhere on the board
/ESP32/GPIO12: U602.20 (GPIO12/TOUCH12/ADC2_CH1/FSPICLK/FSPIIO6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); also elsewhere on the board
/ESP32/GPIO13: U602.21 (GPIO13/TOUCH13/ADC2_CH2/FSPIQ/FSPIIO7/S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)
/ESP32/GPIO14: U602.22 (GPIO14/TOUCH14/ADC2_CH3/FSPIWP/FSPIDQS/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)
/ESP32/GPIO18: U602.11 (GPIO18/U1RXD/ADC2_CH7/CLK_OUT3); also elsewhere on the board
/ESP32/GPIO21: U602.23 (GPIO21); also elsewhere on the board
/ESP32/GPIO38: U602.31 (GPIO38/FSPIWP/SUBSPIWP); also elsewhere on the board
/ESP32/GPIO39: U602.32 (MTCK/GPIO39/CLK_OUT3/SUBSPICS1); also elsewhere on the board
/ESP32/GPIO40: U602.33 (MTDO/GPIO40/CLK_OUT2); also elsewhere on the board
/ESP32/GPIO47: U602.24 (GPIO47/SPICLK_P/SUBSPICLK_P_DIFF); also elsewhere on the board
/ESP32/GPIO48: U602.25 (GPIO48/SPICLK_N/SUBSPICLK_N_DIFF); also elsewhere on the board
/ESP32/I2C_SCL: R605.2, U602.9 (GPIO16/U0CTS/ADC2_CH5/XTAL_32K_N); also elsewhere on the board
/ESP32/I2C_SDA: R607.2, U602.10 (GPIO17/U1TXD/ADC2_CH6); also elsewhere on the board
/ESP32/USB_D+: D602.2 (A2), U602.14 (GPIO20/U1CTS/ADC2_CH9/CLK_OUT1/USB_D+), USB601.A6 (D+), USB601.B6 (D+)
/ESP32/USB_D-: D603.2 (A2), U602.13 (GPIO19/U1RTS/ADC2_CH8/CLK_OUT2/USB_D-), USB601.A7 (D-), USB601.B7 (D-)
/ESP32/VUSB: D601.2 (A2), USB601.A4 (VBUS), USB601.A9 (VBUS), USB601.B4 (VBUS), USB601.B9 (VBUS); also elsewhere on the board
/ESP32/WDI: U601.4 (WDI), U602.8 (GPIO15/U0RTS/ADC2_CH4/XTAL_32K_P)
GND: C601.1, C602.1, C603.2, D601.1 (A1), D602.1 (A1), D603.1 (A1), D605.1 (K), D606.1 (K), R601.2, R602.2, SW101.2, SW601.2, U601.2 (GND), U602.1 (GND), U602.40 (GND), U602.41 (GND), USB601.A1 (GND), USB601.A12 (GND), USB601.B1 (GND), USB601.B12 (GND), USB601.S1 (SHIELD); also elsewhere on the board
unnamed: D604.2 (A), R603.2
unnamed: D605.2 (A), R604.2
unnamed: D606.2 (A), R606.2
unnamed: SW601.1, U601.3 (MR)
unnamed: SW101.1, U602.27 (GPIO0/BOOT)
unnamed: R604.1, U602.34 (MTDI/GPIO41/CLK_OUT1)
unnamed: R606.1, U602.35 (MTMS/GPIO42)
unnamed: R601.1, USB601.A5 (CC1)
unnamed: R602.1, USB601.B5 (CC2)
RESET: D604.1 (K), U601.1 (RESET), U602.3 (EN)
VDD: C601.2, C602.2, C603.1, R603.1, R605.1, R607.1, U601.5 (VDD), U602.2 (3V3); also elsewhere on the board

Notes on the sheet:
ESP32 S3
Watchdog Timer & Reset
Pins: https://github.com/atomic14/esp32-s3-pinouts
USB Type-C Connector
CC pin 56kΩ for 0.5A 22kΩ for 1.5A 10kΩ for 3.0A


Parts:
C301: 10uF; C_0603_1608Metric; LCSC C96446
C302: 100nF; C_0402_1005Metric; LCSC C1525
MICRO_SD301: TF-01A; LCSC C5155563
U301: PCF8563T; SOIC-8_3.9x4.9mm_P1.27mm; LCSC C5795601
Y301: Crystal; Crystal_SMD_3215-2Pin_3.2x1.5mm; LCSC C9002
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

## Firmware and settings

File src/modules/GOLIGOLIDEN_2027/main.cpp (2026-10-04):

#include <library/wobc.h>
#include <components/LiPoPower/lipo_power.h>
#include <components/LoRa/lora.h>
#include <components/Pressure/pressure.h>
#include <components/IMU/IMU.h>
#include <components/GPS/gps.h>
#include <components/Logger/logger.h>
#include <SPI.h>

#define SPI0_CS_PIN     13
#define SPI0_MOSI_PIN   14
#define SPI0_MISO_PIN   47
#define SPI0_SCK_PIN    21

#define GPS_RX_PIN 11
#define GPS_TX_PIN 12

#define LORA_CHANNEL 3
#define LORA_TX_PIN 40
#define LORA_RX_PIN 39
#define LORA_AUX_PIN 38
#define LORA_M0_PIN 43
#define LORA_M1_PIN 44

#define ST 6
#define PG 7
#define STAT1 8
#define STAT2 18
#define HEAT -1
#define CHARGELED 10
#define TEMP -1

#define SD_INSERTED_PIN 48
#define SDCARD_MOSI_PIN SPI0_MOSI_PIN
#define SDCARD_MISO_PIN SPI0_MISO_PIN
#define SDCARD_SS_PIN SPI0_CS_PIN
#define SDCARD_SCK_PIN SPI0_SCK_PIN

constexpr uint8_t module_id = 0x4E;  // GOLIDEN module ID
constexpr uint8_t unit_id = 0x63;

HardwareSerial lora_serial(1);
core::SerialBus serial_bus(Serial);


component::Logger logger(SPI, SPI0_CS_PIN, SD_INSERTED_PIN);
component::GPS gps(GPS_RX_PIN, GPS_TX_PIN, 9600, unit_id, 1);
component::IMU9 imu(Wire, unit_id, 100, 15.0f);  // 発射検知閾値 35 m/s^2 (~3.6G)
component::LoRa lora(LORA_AUX_PIN, LORA_M0_PIN, LORA_M1_PIN, LORA_TX_PIN, LORA_RX_PIN, LORA_CHANNEL, 0);
component::LiPoPower power(Wire, ST, PG, STAT1, STAT2, HEAT, CHARGELED, TEMP, unit_id, 1);


interface::WatchIndicator<unsigned> status_indicator(42, kernel::packetCount());
interface::WatchIndicator<unsigned> error_indicator(41, kernel::errorCount());

class Main : public process::Component {
public:
    Main() : process::Component("main", 0x00) {}
    kernel::Listener my_listener_;
    kernel::Listener heartbeat_;

    void setup() override {
        my_listener_.telemetry(); 
        listen(my_listener_, 8);
        heartbeat_.component(0x4D);
        listen(heartbeat_,1);
    }

    void loop() override {
        while (my_listener_) {
            wcpp::Packet packet = my_listener_.pop();
                wcpp::Packet lorapacket = newPacket(64);
                auto im = packet.find("Im");
                if(!im){
                    lorapacket.command(lora.send_command_id, lora.component_id_base + 0);
                    lorapacket.append("Pa").setPacket(packet);
                    sendPacket(lorapacket);
                }
            }
        }
    }main_;

void setup() {
    Serial.begin(115200);
    kernel::setUnitId(unit_id);
    if (!kernel::begin(module_id, true)) return;

    //Serial0.setPins(4, 5);
    Wire.begin(17, 16);  // SDA=17, SCL=16
    serial_bus.begin();

    SPI.begin(SDCARD_SCK_PIN, SDCARD_MISO_PIN, SDCARD_MOSI_PIN, SDCARD_SS_PIN);

    delay(1000); 

    status_indicator.begin();
    status_indicator.blink_on_change();

    error_indicator.begin();
    error_indicator.set(true);

    power.begin();
    lora.begin();
    //pressure.begin();
    imu.begin();
    gps.begin();
    logger.begin();
    main_.begin();

    error_indicator.set(false);
    error_indicator.blink_on_change(100);
}

void loop() {
    status_indicator.update();
    error_indicator.update();
}

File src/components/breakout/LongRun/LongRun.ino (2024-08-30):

#include <TinyGPSPlus.h>
#include <Arduino.h>
#include <Wire.h>
#include "E220.h"
#include "INA226.h"
#include <Adafruit_Sensor.h>
#include <Adafruit_BME280.h>
#include <SPI.h>
#include <SD.h>
#include <Preferences.h>

Preferences preferences;

#define ERROR 41
#define STAT 42

#define LORA_ADDR E220::BROADCAST
#define LORA_CHANNEL 10
#define LORA_TX_PIN 38
#define LORA_RX_PIN 39
#define LORA_AUX_PIN 40
#define LORA_M0_PIN 12
#define LORA_M1_PIN 11

#define BME_ADDR 0x76
#define SEALEVELPRESSURE_HPA (1013.25)

#define SPI0_SCK_PIN 1
#define SPI0_MOSI_PIN 4
#define SPI0_MISO_PIN 3
#define SPI0_CS_PIN 2

#define SD_INSERTED_PIN 5
#define SDCARD_MOSI_PIN SPI0_MOSI_PIN
#define SDCARD_MISO_PIN SPI0_MISO_PIN
#define SDCARD_SS_PIN SPI0_CS_PIN
#define SDCARD_SCK_PIN SPI0_SCK_PIN

#define SD_TIMEOUT_MS 10

INA226 INA1(0x4F);   // Lipoのコネクタから充放電モジュールまで
INA226 INA2(0x4D);   // 充放電とバックアップからDCDCまで
INA226 INA3(0x4E);   // DCDC後

Adafruit_BME280 bme;

void setBME();
float* getBMEData();
void setupINA();
float* getINAData();
void setupLoRa();

float INAData[6];
float BMEData[3]; // 温度、湿度、気圧の順でデータを保持する配列

char fileName[13];
int fileNumber;

static const int RXPin = 47, TXPin = 48;
static const uint32_t GPSBaud = 38400;

TinyGPSPlus gps;
HardwareSerial ss(2);

HardwareSerial lora_serial(1);
E220 lora(lora_serial, LORA_AUX_PIN, LORA_M0_PIN, LORA_M1_PIN);

unsigned long lastUpdateTime = 0;

void setup() {
  Serial.begin(115200);
  digitalWrite(STAT, HIGH);
  Wire.begin(17, 16);
  ss.begin(GPSBaud, SERIAL_8N1, RXPin, TXPin);
  pinMode(STAT, OUTPUT);
  pinMode(ERROR, OUTPUT);
  SPI.begin(SDCARD_SCK_PIN, SDCARD_MISO_PIN, SDCARD_MOSI_PIN, SDCARD_SS_PIN);
  
  setupLoRa();
  setupINA();
  setBME();

  delay(500);
  if (!SD.begin(SDCARD_SS_PIN)) { 
    Serial.println(F("Card failed, or not present")); 
    digitalWrite(ERROR, HIGH);
    return;
  }
  Serial.println(F("SD ok."));
}

void loop() {
  char gpsData[64];
  char VI[50];
  char TH[50];

  preferences.begin("my-app", false);
  fileNumber = preferences.getInt("value", 0);
  snprintf(fileName, sizeof(fileName), "/file%d.txt", fileNumber);
  File dataFile = SD.open(fileName, FILE_WRITE);

  if (dataFile) {
    dataFile.println("V1,I1,V2,I2,V3,I3,Temp,Hum,Press,lat,lng,month,day,hour,min,sec");
  } else {
    Serial.println("Failed to open file for writing");
    digitalWrite(ERROR, HIGH);
    return;
  }
  fileNumber++;
  preferences.putInt("value", fileNumber);
  preferences.end();

  for (int i = 0; i < 600; i++) {
    digitalWrite(STAT, HIGH);
    float* inadata = getINAData();
    snprintf(VI, sizeof(VI), "%.2f,%.2f,%.2f,%.2f,%.2f,%.2f,", inadata[0], inadata[1], inadata[2], inadata[3], inadata[4], inadata[5]);
    dataFile.print(VI);

    float* bmedata = getBMEData();
    snprintf(TH, sizeof(TH), "%.2f,%.2f,%.2f,", bmedata[0], bmedata[1], bmedata[2]);
    dataFile.print(TH);

    unsigned long currentTime = millis();

    if (currentTime - lastUpdateTime >= 3000) {
      lastUpdateTime = currentTime;

      lora.sendTransparent((const uint8_t*)VI, strlen(VI));
      delay(1000);
      lora.sendTransparent((const uint8_t*)TH, strlen(TH));
      delay(1000);
    }

    while (ss.available() > 0) {
      gps.encode(ss.read());
    }

    if (gps.charsProcessed() < 10 && millis() > 5000) {
      Serial.println(F("No GPS data received: check wiring"));
    }

    if (gps.location.isUpdated()) {
      float lat = gps.location.lat();
      float lng = gps.location.lng();
      int month = gps.date.month();
      int day = gps.date.day();
      int hour = (gps.time.hour() + 9) % 24;
      int min = gps.time.minute();
      int sec = gps.time.second();
      sprintf(gpsData, "%.6f,%.6f,%02d,%02d,%02d,%02d,%02d", lat, lng, month, day, hour, min, sec);
      dataFile.print(gpsData);
      digitalWrite(STAT, LOW);
      lora.sendTransparent((const uint8_t*)gpsData, strlen(gpsData));
      delay(1000);
    }
    dataFile.println();
    i++;
    dataFile.flush();
    delay(2000);
  }
  dataFile.close();
}

void setupLoRa() {
  lora_serial.begin(9600, SERIAL_8N1, LORA_RX_PIN, LORA_TX_PIN);

  lora.begin();
  bool ok = true;
  ok &= lora.setMode(E220::Mode::CONFIG_DS);
  ok &= lora.setParametersToDefault();
  ok &= lora.setSerialBaudRate(115200);
  ok &= lora.setDataRate(E220::SF::SF9, E220::BW::BW125kHz);
  ok &= lora.setEnvRSSIEnable(true);
  ok &= lora.setSendMode(E220::SendMode::TRANSPARENT);
  ok &= lora.setModuleAddr(LORA_ADDR);
  ok &= lora.setChannel(LORA_CHANNEL);
  ok &= lora.setRSSIEnable(true);
  ok &= lora.setMode(E220::Mode::NORMAL);

  lora_serial.flush();
  lora_serial.begin(115200);

  delay(100);

  if (ok) {
    Serial.println("LoRa setup complete.");
  } else {
    Serial.println("LoRa setup error.");
  }
}

void setupINA() {
  INA1.begin();
  INA1.setMaxCurrentShunt(1, 0.05);
  INA2.begin();
  INA2.setMaxCurrentShunt(1, 0.05);
  INA3.begin();
  INA3.setMaxCurrentShunt(1, 0.05);
}

float* getINAData() {
  INAData[0] = INA1.getBusVoltage();
  INAData[1] = INA1.getCurrent_mA();
  INAData[2] = INA2.getBusVoltage();
  INAData[3] = INA2.getCurrent_mA();
  INAData[4] = INA3.getBusVoltage();
  INAData[5] = INA3.getCurrent_mA();
  return INAData;
}

void setBME() {
  unsigned status;
  status = bme.begin(BME_ADDR, &Wire);
  delay(200);
  if (!status) {
    while (1) delay(10);
  }
  delay(1000);
}

float* getBMEData() {
  BMEData[0] = bme.readTemperature();
  BMEData[1] = bme.readHumidity();
  BMEData[2] = bme.readPressure() / 100.0F;
  return BMEData;
}

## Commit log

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2023-11-02 コンポーネント用テンプレートを追加
    [Tempelate.kicad_pcb, Tempelate.kicad_sch]
2023-11-09 TWELITEのBBDモデルの回路図です。
    [TWELITE.kicad_pcb, TWELITE.kicad_sch]
2023-11-15 初コミット
    [SLAM.kicad_pcb, SLAM.kicad_sch, Tempelate.kicad_sch]
2023-11-16 IMU大体完成？
    [IMU.kicad_pcb, IMU.kicad_sch]
2023-11-16 IMU更新
    [GPS.kicad_pcb, GPS.kicad_sch, IMU.kicad_pcb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]
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2023-11-16 GPS更新
    [GPS.kicad_pcb, GPS.kicad_sch]
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2023-11-16 LiPo充放電コントローラの変換基板です。クリアランスでエラー出てますけど、ライブラリーにあった1005のだと発生してしまうようで設定の直し方わからなかったので放置しました。 確認お願いします。
    [MCP73871.kicad_pcb, MCP73871.kicad_sch]
2023-11-17 tempelate戻して、変換ボードをbreakoutに入れました。
    [GPS.kicad_pcb, GPS.kicad_sch, IMU.kicad_pcb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]
2023-11-17 変換基板の場所を移しました。確認お願いします。
    [MCP73871.kicad_pcb, MCP73871.kicad_sch, TWELITE.kicad_pcb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]
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2023-11-17 GPS breakout board にアンテナを追加
    [GPS.kicad_pcb, GPS.kicad_sch]
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2023-11-19 カメラモジュール試作完成
    [ESP32Camera.kicad_pcb, ESP32Camera.kicad_sch]
2023-11-19 ブレークアウト基板発注用面付け
    [202311.kicad_pcb, 202311.kicad_sch]
2023-11-20 異種面付けにならないよう修正
    [202311.kicad_pcb]
2023-11-22 First Uplode
    [Tempelate.kicad_pcb, Tempelate.kicad_sch, WOBC_無線点火装置module.kicad_pcb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]
2023-11-27 抵抗値一部追加
    [WOBC_無線点火装置module.kicad_sch]
2024-01-11 New Changes 20240111
    [WOBC_無線点火装置module.kicad_sch]
2024-02-08 LiPo電源基板 回路図
    [LiPo_1Cell.kicad_sch, Power.kicad_pcb, Power.kicad_sch]
2024-02-13 Almost Complete
    [WOBC_無線点火装置module.kicad_pcb, WOBC_無線点火装置module.kicad_sch]
2024-02-15 SLAMは一応完成しました
    [LiPo_1Cell.kicad_sch, Power.kicad_pcb, Power.kicad_sch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]
2024-02-18 4枚から3枚に減らせました
    [WOBC_無線点火装置-B_Cu.gbl, WOBC_無線点火装置-B_Mask.gbs, WOBC_無線点火装置-B_Paste.gbp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]
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2024-03-21 LiPo電源モジュールの修正，地上局用簡易版の追加
    [LiPoPower.kicad_pcb, LiPoPower.kicad_sch, LiPoPowerSimple.kicad_sch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]
2024-03-21 ESP32コア追加
    [ESP32Core.kicad_pcb, ESP32Core.kicad_sch]
2024-03-21 SDカードロガー・RTCコンポ追加
    [Logger.kicad_sch]
2024-03-21 Module接続部追加
    [ModuleIF.kicad_pcb, ModuleIF.kicad_sch, ModuleIFSimple.kicad_sch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]
2024-03-21 規格基板修正
2024-03-21 ロックーンバスモジュール(WIP)
    [BasicOBC.kicad_pcb, BasicOBC.kicad_sch, LiPoPower.kicad_pcb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]
2024-03-22 LoRa回路図です。確認お願いします。
    [LoRa.kicad_pcb, LoRa.kicad_sch]
2024-03-22 バックアップ電源とヒーター用のロードスイッチは定格オーバーだったので，MOSFETに変更
    [LiPoPower.kicad_pcb, LiPoPower.kicad_sch]
2024-03-22 バックアップ電源切り替えの論理が間違っていたので反転
    [LiPoPower.kicad_pcb, LiPoPower.kicad_sch]
2024-03-23 RP2040Coreを追加
    [RP2040Core.kicad_pcb, RP2040Core.kicad_sch]
2024-03-24 LoRaコンポーネント訂正しました。確認お願いします。
    [LoRa.kicad_sch]
2024-03-24 LCD回路図とコードです。確認お願いします。
    [LCD.kicad_pcb, LCD.kicad_sch]
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2024-03-29 LoRaのコンポーネント基板設計ができました。SMAコネクタですが、秋月のサイズが既存のフットプリントと寸法が異なっていたので、フットプリント追加しています。
    [LoRa.kicad_pcb, LoRa.kicad_sch]
2024-03-29 SLAMパスコン追加、プルアップ削除
    [SLAM.kicad_sch]
2024-04-05 バックアップ切り替え回路修正
    [LiPoPower.kicad_pcb, LiPoPower.kicad_sch, LiPoPowerSimple.kicad_pcb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]
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2024-04-06 リンク修正
2024-04-06 部品変更を反映
    [LiPoPower.kicad_pcb, LiPoPower.kicad_sch]
2024-04-07 ごちゃごちゃになったので一回コミットします。 GPSとLiPoとLoRaの一部が変化してると思います。
    [GPS.kicad_pcb, GPS.kicad_sch, LiPoPower.kicad_sch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]
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2024-04-11 いろいろ変えました
    [9DoF.kicad_pcb, 9DoF.kicad_sch, GPS.kicad_sch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]
2024-04-11 自分の担当分を追加しました
    [ESP32Core.kicad_pcb, ESP32Core.kicad_sch, LiPoPower.kicad_pcb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]
2024-04-13 RP2040・LiPo・LoRa・ModuleIF・LCDのLCSC割り当て完了しました．基板設計中に確認していただきたいです． 何点か変更があります．LiPoPowerSimpleの充放電ICのProg周辺の抵抗値がLiPoPowerと異なっていたので合わせてしまっています． 今，ModuleIFのロードセルが指定されていたものではJLCPCBに在庫がなく，同じシリーズの在庫が多少残っているも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
    [GPS.kicad_pcb, GPS.kicad_sch, LCD.kicad_pcb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]
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2024-04-13 マージしたので，これでうまくいってほしいです．
    [LiPoPower.kicad_pcb, LiPoPower.kicad_sch, LiPoPowerSimple.kicad_pcb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]
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2024-04-18 ESDダイオードの変更などです。GSはまだ作りかけなので参考にしないでください
    [ESP32Core.kicad_pcb, ESP32Core.kicad_sch, GS.kicad_pcb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]
2024-04-18 LCSC部品番号割り当て
    [9DoF.kicad_pcb, 9DoF.kicad_sch, ESP32Core.kicad_pcb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]
2024-04-18 SMAコネクタ・ロードスイッチ、groveコネクタについて修正しました
    [LoRa.kicad_pcb, LoRa.kicad_sch, ModuleIF.kicad_pcb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]
2024-04-18 SMAコネクタ等ちょいちょい変更しました
    [9DoF.kicad_sch, GPS_active.kicad_pcb, GPS_active.kicad_sch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]
2024-04-19 Trackerモジュールを作り始めました。あと、GPSのTX,RXを階層ラベルに変更しました。
    [9DoF.kicad_sch, ESP32Core.kicad_sch, GPS_active.kicad_sch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]
2024-04-20 LCD基板の大幅変更とそれに伴うフットプリント・シンボルライブラリの追加
    [GS.kicad_pcb, GS.kicad_sch, LCD.kicad_pcb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]
2024-04-20 コメントもらった分修正加えました。LiPoのLCSC、RP2040CoreのUSB-C、LCDのプルアップ抵抗です。 USB-Cはフットプリント作ったやつで不安なので、確認してもらいたいです。
    [LCD.kicad_sch, LiPoPower.kicad_sch, RP2040Core.kicad_pcb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]
2024-04-23 諸々修正しました
    [9DoF.kicad_sch, ESP32Core.kicad_sch, GPSActive.kicad_pcb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]
2024-04-24 USB-Cのフットプリントの変更・GSモジュールの回路図配線完了しました。 Coreの方はUSB-Cのフットプリント修正してますので、こちらを使ってもらえればと思います。
    [ESP32Core.kicad_pcb, ESP32Core.kicad_sch, GS.kicad_sch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]
2024-04-25 trackerにlipoを加え忘れてたので追加しました
    [LiPoPower.kicad_pcb, LiPoPower.kicad_sch, LiPoPowerSimple.kicad_pcb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]
2024-04-25 LoRaドライバ修正
2024-04-26 モジュールのファイル作成と、回路図の貼り付けを行いました。LoRaモジュールは配線とDLCチェックまで終わってます。時間があるときに確認お願いします。
    [Controller.kicad_pcb, Controller.kicad_sch, GS.kicad_pcb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]
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2024-04-27 LoRaモジュールに3.3Vレギュレータ入れました。 コネクタ増やしたんですけどスペースないので片方表、片方裏です。GSを作ってみてコネクタが表にくるか裏に来るか考えてから判断します。必要に迫られればLoRaを裏に移動します。 あとnasuのブランチからセンサ類のコンポーネント引っ張ってきました。
    [9DoF.kicad_pcb, 9DoF.kicad_sch, GPSActive.kicad_pcb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]
2024-05-02 GSモジュールは一応の完成です。その代わりLoRaのモジュールの修正が必要になりました。
    [ESP32Core.kicad_sch, GPSPassive.kicad_sch, GS.kicad_pcb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]
2024-05-03 Trackerとりあえず並べました
    [ESP32Core.kicad_sch, GPSActive.kicad_sch, LiPoPower.kicad_sch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]
2024-05-04 9DoFの配線をしました
    [9DoF.kicad_pcb]
2024-05-04 ちょっと修正しました
    [9DoF.kicad_pcb]
2024-05-04 主にControllerの更新です
    [Controller.kicad_pcb, Controller.kicad_sch, GS.kicad_pcb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]
2024-05-04 LoRaモジュールも併せて更新します。コネクタを両方表面に持ってきてます
    [LoRa.kicad_pcb]
2024-05-09 espを引っ込めて、SMAが離れるように並びを調整しました
    [Tracker.kicad_pcb]
2024-05-09 9DoFの名前をIMUに変更しました
    [IMU.kicad_pcb, IMU.kicad_sch]
2024-05-16 GS修正版です
    [GS.kicad_pcb]
2024-05-22 Controllerの訂正です．レギュレータを追加追加したのと，差動通信線は平行にしてあります． 広範囲でベタをなくしたのは下層にＧＰＳアンテナがあるため削除したのですが，不必要ですか？確認お願いします．
    [Controller.kicad_pcb, Controller.kicad_sch, GS.kicad_pcb]
2024-05-22 LoRaの全面的な配置変更，シルクを整えました．GSはこれで完了なのでWOBCの場で確認いただきたいです．
    [Controller.kicad_pcb, GS.kicad_pcb, LoRa.kicad_pcb]
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2024-05-26 一部部品の割り当てを修正しました．確認お願いします．
    [Controller.kicad_pcb, ESP32Core.kicad_sch, LiPoPowerSimple.kicad_sch]
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2024-06-04 部品の割り当てやGPSモジュールのフットプリント修正などです。
    [Controller.kicad_pcb, ESP32Core.kicad_sch, GPSPassive.kicad_sch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]
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2024-06-07 c105のフットプリント変更に伴う修正
    [Logger.kicad_sch, Tracker.kicad_pcb]
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2024-06-13 各コンポーネントの修正をしました．一度プッシュします(多分コンフリクトするので)．
    [Controller.kicad_pcb, Controller.kicad_sch, ESP32Core.kicad_pcb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]
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2024-08-02 Mission基板のオーダーファイルの作成・コンポーネント修正（LiPoバックアップ切り替え、GNSS書き込み、usbプルダウン抵抗）
    [ESP32Core.kicad_pcb, ESP32Core.kicad_sch, GPSActive.kicad_pcb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]
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2024-08-06 Igniteコンポーネントの作成とTrackerモジュールの修正
    [Ignite.kicad_pcb, Ignite.kicad_sch, LiPoPower.kicad_sch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]
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2024-08-07 電源回路を修正しました。 ヒーターのダミーロードはどうするか思いつかなかったので、そのままにしています。
    [LiPoPower.kicad_pcb, LiPoPower.kicad_sch, LiPoPowerSimple.kicad_pcb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]
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2024-08-07 RCSインジケータ修正＋ロードセル周辺回路追加
    [HX711.kicad_pcb, HX711.kicad_sch, RCS.kicad_sch]
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2024-08-07 配置一部修正
    [RCS.kicad_pcb]
2024-08-08 Igniteコンポーネントの修正
    [IGN.kicad_pcb, IGN.kicad_sch, Ignite.kicad_sch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]
2024-08-08 usbポートのプルアップ抵抗のCSL修正
    [ESP32Core.kicad_sch, GPSActive.kicad_sch, Tracker.kicad_pcb]
2024-08-08 MissionBus配線完了です。 ベタとか粗いので、これからさらに修正します
    [9DoF.kicad_sch, ESPCore.kicad_sch, GPS.kicad_sch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]
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2024-08-09 GS修正＋発注ファイルにGSのデータを反映
    [ESP32Core.kicad_sch, GPSPassive.kicad_sch, GS.kicad_pcb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]
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2024-08-09 Tracker諸々の修正
    [ESP32Core.kicad_sch, GPSActive.kicad_sch, LiPoPower.kicad_pcb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]
2024-08-09 RCS基板修正
    [RCS.kicad_pcb, RCSComp.kicad_sch, Tank1.kicad_sch]
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2024-08-09 CANバス対応，コアバグ修正
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2024-08-09 一部Tracker修正（Boot追加、Heater用のピンを追加）
    [ESP32Core.kicad_sch, LiPoPower.kicad_sch, Tracker.kicad_pcb]
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2024-08-10 MissionBusモジュール修正
    [9DoF.kicad_sch, ESPCore.kicad_sch, GPS.kicad_sch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]
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2024-08-11 RCS関連コンポーネント修正
    [RCS.kicad_pcb, RCS.kicad_sch, TankPressure.kicad_pcb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]
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2024-08-11 発注基板修正完了
    [GS.kicad_sch, Logger.kicad_sch, MissionBus.kicad_sch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]
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2024-08-14 回路図修正
    [Ignite.kicad_sch]
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2024-08-15 通信試験用プログラム修正（2チャンネルの通信を可能にしました）
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2024-08-16 IGNモジュールの修正
    [IGN.kicad_pcb, IGN.kicad_sch, Ignite.kicad_sch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]
2024-08-16 ロケット電装修正
    [9DoF2.kicad_sch, ESP32Core2.kicad_sch, GPS SAM-M10Q2.kicad_sch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]
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2024-08-16 CAN周りの修正・レギュレータ追加
    [IGN.kicad_pcb, IGN.kicad_sch]
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2024-08-16 ファイル再修正
    [IGN.kicad_pcb, IGN.kicad_sch]
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2024-08-16 不具合修正
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2024-08-30 Controllet基板一部修正です、LCDのピン配置ミスってて修正も難しいのでLCDのるもののみ再発注する予定です。
    [Controller.kicad_pcb]
2024-08-30 シャント抵抗の修正，MOSFETとトランジスタを手はんだのモノに変更，1Ωの抵抗追加
    [IGN.kicad_pcb, Ignite.kicad_sch, RP2040Core.kicad_sch]
2024-08-30 発注基板修正
    [9DoF2.kicad_sch, ESP32Core2.kicad_sch, GPS SAM-M10Q2.kicad_sch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]
2024-08-31 LCSC等修正しました．
    [IGN.kicad_pcb, Ignite.kicad_sch]
2024-08-31 ・ブザー一つ消してAlertピンもなくしました． ・スイッチ2をなくしました． ・１Ωの抵抗を部品変更しました． ・MOSFETとトランジスタのピン配置を修正しました． ・スイッチ1を定格5Aの防水トグルスイッチにするためにフットプリントをXH3ピンに変更しました
    [IGN.kicad_pcb, IGN.kicad_sch, Ignite.kicad_sch]
2024-09-01 ・配置修正(点火電流と信号線が交差しないようにしました) ・サーミスタのピンをADCに変更 ・スイッチのコネクタを3ピンから2ピンに変更
    [IGN.kicad_pcb, IGN.kicad_sch, Ignite.kicad_sch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]
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2024-09-05 docsファイル一部修正
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2024-09-13 CANバスを修正
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2024-09-13 ini修正
2024-09-14 CANloraを同時に動かせるように修正
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2024-09-15 telemeter修正
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2024-09-16 Tracker受信コード修正
2024-09-17 気圧高度とGPS受信の修正
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2025-08-06 コネクタを変更 CAN周りをちょっと修正
    [IF.kicad_sch, RCS.kicad_pcb, RCS.kicad_sch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]
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2025-08-20 ちょっと修正
    [MissionBus.kicad_pcb]
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2025-08-22 配線されてないかったとこを修正．．．
    [GPS.kicad_sch, LiPo.kicad_sch, Logger.kicad_sch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]
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2025-09-08 SDカードのピン割り当て修正
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2026-03-07 再度修正
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2026-03-07 色々修正
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2026-03-29 Fix typo in title of GitHub Copilot manual
    修正
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
